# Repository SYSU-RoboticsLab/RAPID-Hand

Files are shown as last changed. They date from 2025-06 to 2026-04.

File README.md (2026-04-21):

<p align="center">
    <h1 align="center"><strong>
    RAPID Hand: A Robust, Affordable,<br>
    Perception-Integrated, Dexterous Manipulation Platform<br>
    for Generalist Robot Autonomy</strong>
    </h1>
</p>

<p align="center" style="font-size:18px;">
    <a href="https://jeffreyzhaoliang.github.io/zhaoliang-wan.github.io/"><strong>Zhaoliang Wan</strong></a>
    ·
    <a href=""><strong>Zetong Bi</strong></a>
    ·
    <a href=""><strong>Zida Zhou</strong></a>
    ·
    <a href="https://hren20.github.io/"><strong>Hao Ren</strong></a>
    ·
    <a href="https://jzengym.github.io/JZENGYM/"><strong>Yiming Zeng</strong></a>
    ·
    <a href=""><strong>Yihan Li</strong></a>
    <br>
    <a href="http://luqi.info/"><strong>Lu Qi</strong></a>
    ·
    <a href="https://people.ucas.edu.cn/~XuYang"><strong>Xu Yang</strong></a>
    ·
    <a href="https://faculty.ucmerced.edu/mhyang/"><strong>Ming-Hsuan Yang</strong></a>
    ·
    <a href="https://cse.sysu.edu.cn/teacher/ChengHui"><strong>Hui Cheng</strong></a>
</p>

<p align="center">
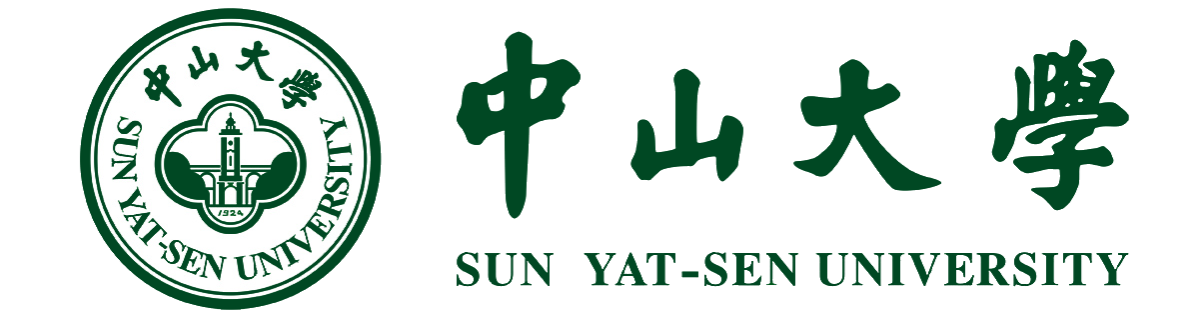
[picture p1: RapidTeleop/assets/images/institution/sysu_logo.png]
  
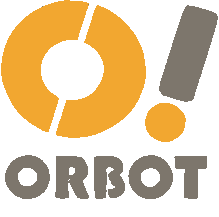
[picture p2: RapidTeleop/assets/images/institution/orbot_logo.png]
  
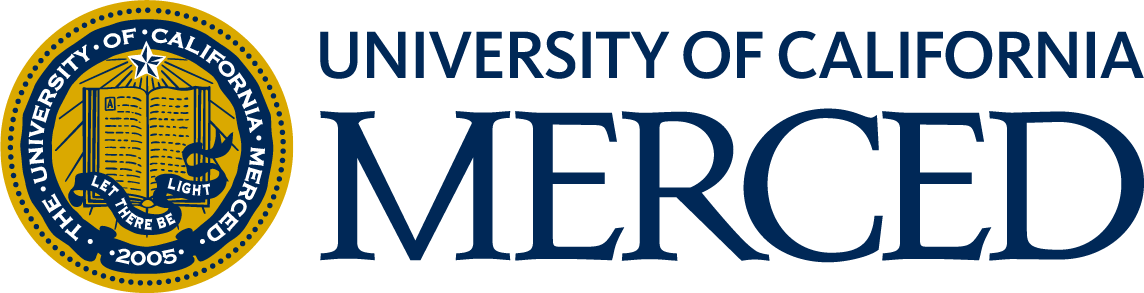
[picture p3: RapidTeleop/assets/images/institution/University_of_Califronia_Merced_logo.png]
  
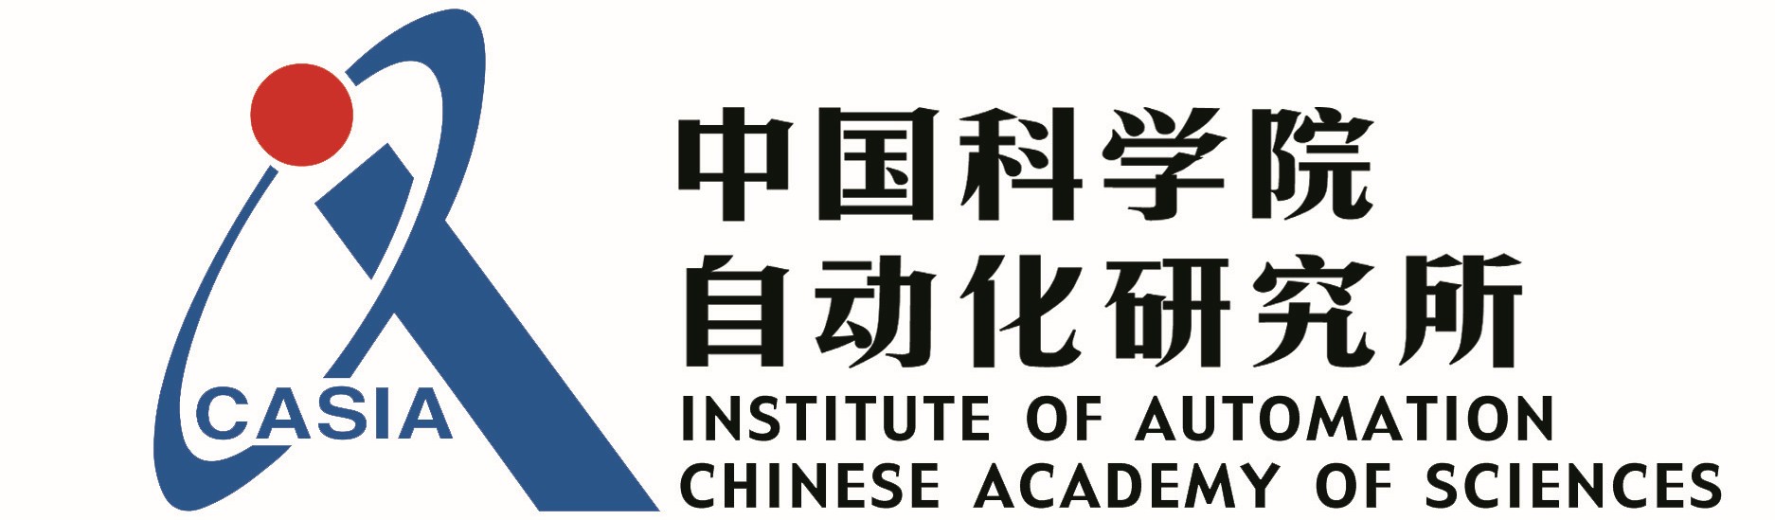
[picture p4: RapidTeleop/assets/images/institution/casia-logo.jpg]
  
</p>

<h3 align="center"> NeurIPS 2025 </h3>

<h3 align="center"><a href="https://www.arxiv.org/abs/2506.07490">Paper</a> | <a href="https://rapid-hand.github.io/">Project Page</a> | <a href="https://github.com/SYSU-RoboticsLab/RAPID-Hand/tree/main/RapidHandHardware">Hardware Design</a> | <a href="https://github.com/SYSU-RoboticsLab/RAPID-Hand/tree/main/RapidTeleop">Teleoperation</a> </a></h3>

<p align="center">
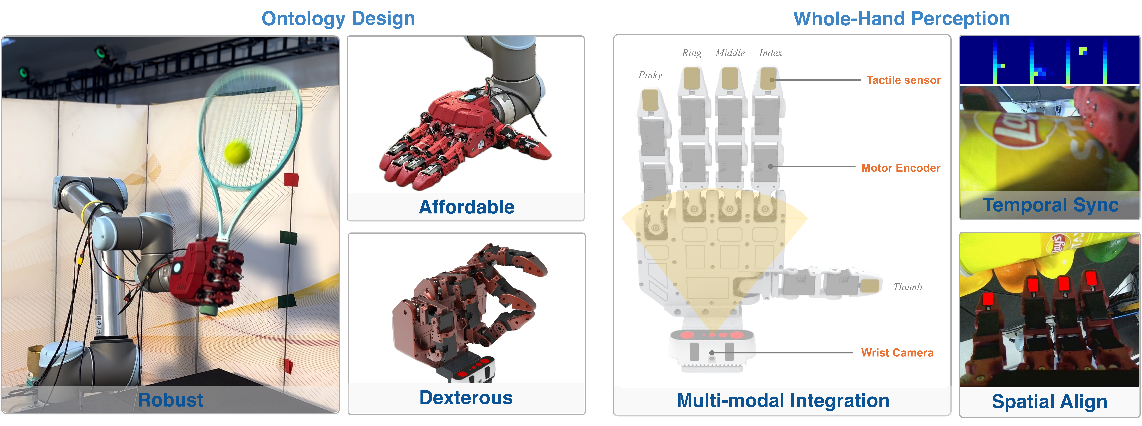
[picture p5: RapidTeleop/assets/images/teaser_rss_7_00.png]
    
</p>

## 🔥 News

- [2025-09] Our paper has been **accepted by NeurIPS 2025**! 🎉
- [2025-06] RAPID Hand full system released with mechanical, electrical, and software modules.
- [2025-06] We release the [paper](https://www.arxiv.org/abs/2506.07490) of RAPID Hand.

---

## 🏠 Introduction

This repository is an official implementation of **RAPID Hand**, which is a low-cost, high-fidelity, modular hardware-software platform for dexterous hand manipulation, consisting of:

- **RapidHandHardware**: Detailed hardware design (PCBs, 3D printable parts, bill of materials).
- **RapidTeleop**: Vision-guided teleoperation suite with intuitive user control.

It enables researchers and hobbyists to easily replicate complex hand hardware for manipulation tasks at a much lower cost.

---

## 🛠️ Installation & Usage

Please refer to the sub-repository READMEs for detailed instructions:

- 🧩 [RapidHandHardware](./RapidHandHardware/README.md): mechanical design, PCB setup, and system integration for the RAPID Hand platform.
- 🖥️ [RapidTeleop](./RapidTeleop/README.md): teleoperation interface, ROS setup, and control pipeline for both simulation and real hardware.

---

## 📝 TODO

- \[x\] Release hardware and BOM.
- \[x\] Upload software for teleop and control.
- \[ \] Extend to multiple hand variants and task types.

---

## 🔗 Citation

If you use our project, please cite:

```bibtex
@article{wan2025rapid,
  title={RAPID Hand: A Robust, Affordable, Perception-Integrated, Dexterous Manipulation Platform for Generalist Robot Autonomy},
  author={Wan, Zhaoliang and Bi, Zetong and Zhou, Zida and Ren, Hao and Zeng, Yiming and Li, Yihan and Qi, Lu and Yang, Xu and Yang, Ming-Hsuan and Cheng, Hui},
  journal={arXiv preprint arXiv:2506.07490},
  year={2025}
}
```

---

## 📄 License

This project is licensed under the [Creative Commons BY-NC-SA 4.0 License](http://creativecommons.org/licenses/by-nc-sa/4.0/).

---

## 🙏 Acknowledgements

This project was developed with help of the following codebases.
- [Tracking Streamer](https://github.com/Improbable-AI/VisionProTeleop)  
- [AnyTeleop](https://yzqin.github.io/anyteleop/)  
- [Bunny-VisionPro](https://dingry.github.io/projects/bunny_visionpro.html)  
- [HATO](https://toruowo.github.io/hato/)  
- [Orbbec-sdk](https://github.com/orbbec/pyorbbecsdk)  

We would also like to thank orbot **ORBOT** Ltd. for their support on the robot hardware and [LUSTER](https://www.luster3ds.com/content/details202_5099.html) for motion capture devices. We sincerely appreciate the contributions from all related institutions and authors.

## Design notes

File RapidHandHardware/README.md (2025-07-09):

<p align="center">
    <h1 align="center"><strong>
    RAPID Hand: A Robust, Affordable,<br>
    Perception-Integrated, Dexterous Manipulation Platform<br>
    for Generalist Robot Autonomy</strong>
    </h1>
</p>

<p align="center" style="font-size:18px;">
    <a href="https://jeffreyzhaoliang.github.io/zhaoliang-wan.github.io/"><strong>Zhaoliang Wan</strong></a>
    ·
    <a href=""><strong>Zetong Bi</strong></a>
    ·
    <a href=""><strong>Zida Zhou</strong></a>
    ·
    <a href="https://hren20.github.io/"><strong>Hao Ren</strong></a>
    ·
    <a href="https://jzengym.github.io/JZENGYM/"><strong>Yiming Zeng</strong></a>
    ·
    <a href=""><strong>Yihan Li</strong></a>
    <br>
    <a href="http://luqi.info/"><strong>Lu Qi</strong></a>
    ·
    <a href="https://people.ucas.edu.cn/~XuYang"><strong>Xu Yang</strong></a>
    ·
    <a href="https://faculty.ucmerced.edu/mhyang/"><strong>Ming-Hsuan Yang</strong></a>
    ·
    <a href="https://cse.sysu.edu.cn/teacher/ChengHui"><strong>Hui Cheng</strong></a>
</p>

<h3 align="center"><a href="https://www.arxiv.org/abs/2506.07490">Paper</a> | <a href="https://rapid-hand.github.io/">Project Page</a> | <a href="https://github.com/SYSU-RoboticsLab/RAPID-Hand/tree/main/RapidTeleop">Teleoperation</a> </a></h3>

<p align="center">
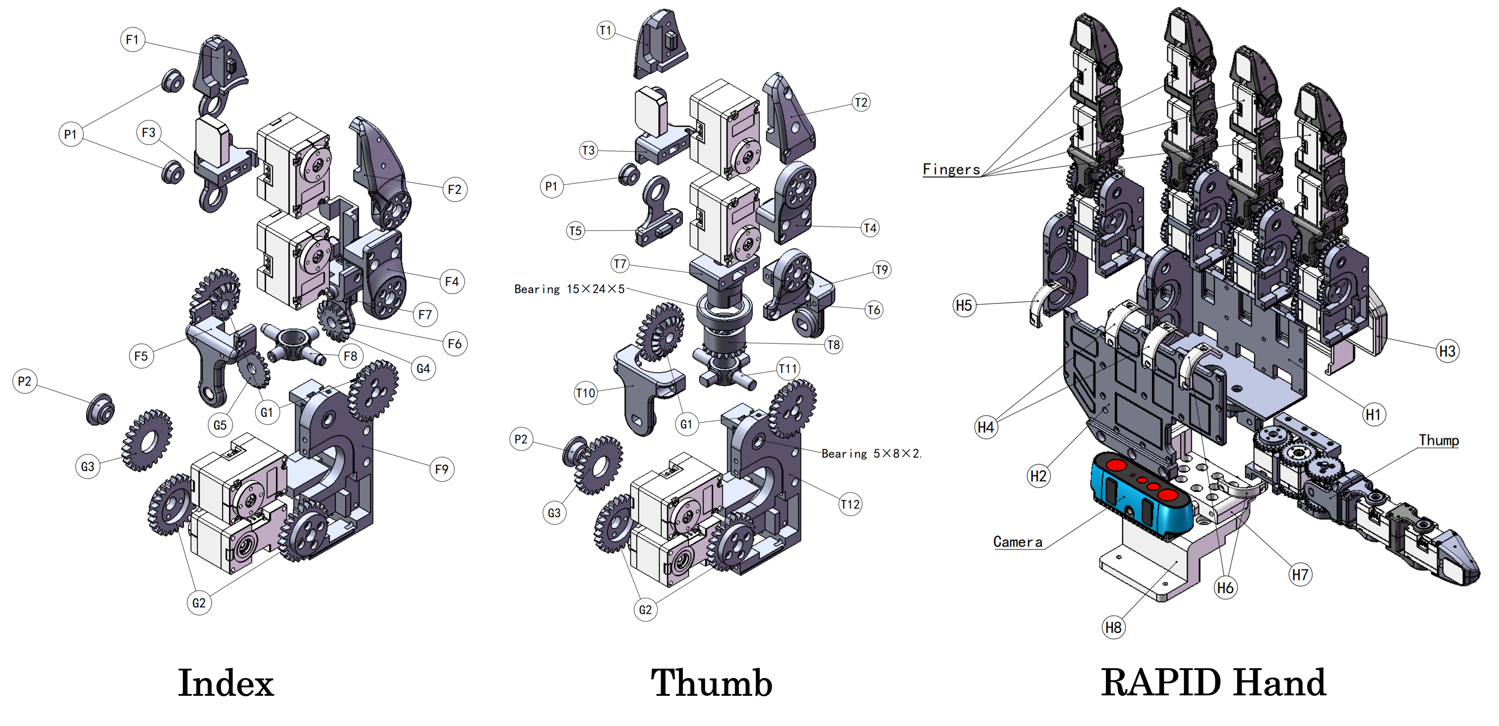
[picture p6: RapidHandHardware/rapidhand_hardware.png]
    
</p>

---

## 1. Introduction

This repository provides full open-source hardware and software resources for **RAPID Hand**. It enables reproducible development and robust sensorimotor integration for manipulation.

---

## 2. Quick Start Guide

> This section walks through the end-to-end hardware setup, including 3D printing, PCB assembly, and full system integration.

### 2.1 Mechanical Assembly

Instructions are located in the `mechanical_structure/` directory, including:

- `.STL` and `.STEP` files for 3D printing
- Servo model references and mounting instructions
- Camera and base installation guide

📎 **Goal**: Physical hand structure assembled with camera mounted.

---

### 2.2 PCB Sourcing & Assembly

PCB instructions are found in the `pcb_sync_module/` directory and include:

- `BOM_Board1_PCB1.xlsx`: Bill of Materials
- `SCH_Schematic1.pdf`: Circuit schematic

📎 **Goal**: PCB modules soldered, verified, and connected to camera/tactile sensors.

---

## 3. Software Setup & Testing

This section covers environment setup, actuator calibration, camera integration, and tactile sensor verification to ensure the system is fully functional.

### 3.1 Environment Setup

Create and initialize a Conda environment named `rapid_hand_env`:

```bash
conda create -n rapid_hand_env python=3.8
conda activate rapid_hand_env
pip install -r requirements.txt
```

---

### 3.2 Dynamixel Motor Calibration

#### ⚙️ Zero-Position Calibration

1. **Close** Dynamixel Wizard if open.
2. Mount the calibration fixture and manually align fingers into a **zero (neutral) pose**.
3. Run the calibration script (replace with actual port, e.g., `/dev/ttyUSB0`):

```bash
python motor_init -p <your_motor_port>
```

4. Verify the zero position (with the calibration fixture removed):

```bash
python motor_init -p <your_motor_port> --test
```

> The hand should return to the neutral pose without joint misalignment.

#### 🤖 Gesture Test

After calibration, run a test sequence to validate motor setup:

```bash
python motion_sequence_controller -p <your_motor_port>
```

> The hand should perform predefined gestures (e.g., curling) smoothly and without collisions.

---

### 3.3 Camera Setup and Testing

#### 🧰 SDK Installation

> For detailed installation instructions, refer to the [Official Orbbec SDK Documentation](https://orbbec.github.io/pyorbbecsdk/source/2_installation/build_the_package.html)

Run the following commands to install and export the camera SDK:

```bash
cd control/rapid_hand_control/camera_port
git submodule add https://github.com/orbbec/pyorbbecsdk.git
conda activate rapid_hand_env
bash build_sdk.sh
```

> Shared libraries will be placed in `camera_sdk/` for use.

#### 🔌 Device Connection and Test

Connect the Orbbec camera via **USB 3.0** for reliable transmission. Run:

```bash
python hello_orbbec.py
```

Expected terminal output:

```txt
Hello Orbbec!
SDK version: 2.3.5
Device info: DeviceInfo(name=Orbbec Gemini 335, ...)
```

#### 🔐 Serial Number Configuration

Copy the `serial_number` from the output above and insert it into:

```json
// rapid_hand_control/camera_port/multi_device_sync_config.json
"devices": [
  {
    "serial_number": "YOUR_SERIAL",
    "config": {
      "mode": "HARDWARE_TRIGGERING"
    }
  }
]
```

---

### 3.4 Tactile Sensor Visualization

Run the following script to monitor tactile feedback in real-time:

```bash
python tactile_visualizer -p <your_serial_port>
```

> Use this to verify the sensor layout and ensure signal consistency across all fingers.

---

## 4. FAQ & Troubleshooting

Common issues and suggested checks:

- **Motor not responding** → Check power supply and USB permissions
- **No tactile signal** → Confirm sensor wiring and PCB soldering
- **PCB not powering up** → Check voltage and shorts across power lines
- *(Feel free to contribute more entries!)*

---

## Citation

```bibtex
@article{wan2025rapid,
  title={RAPID Hand: A Robust, Affordable, Perception-Integrated, Dexterous Manipulation Platform for Generalist Robot Autonomy},
  author={Wan, Zhaoliang and Bi, Zetong and Zhou, Zida and Ren, Hao and Zeng, Yiming and Li, Yihan and Qi, Lu and Yang, Xu and Yang, Ming-Hsuan and Cheng, Hui},
  journal={arXiv preprint arXiv:2506.07490},
  year={2025}
}
```

---

## License

This project is licensed under the [Creative Commons BY-NC-SA 4.0 License](http://creativecommons.org/licenses/by-nc-sa/4.0/).

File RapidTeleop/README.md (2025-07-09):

<p align="center">
    <h1 align="center"><strong>
    RAPID Hand: A Robust, Affordable,<br>
    Perception-Integrated, Dexterous Manipulation Platform<br>
    for Generalist Robot Autonomy</strong>
    </h1>
</p>

<p align="center" style="font-size:18px;">
    <a href="https://jeffreyzhaoliang.github.io/zhaoliang-wan.github.io/"><strong>Zhaoliang Wan</strong></a>
    ·
    <a href=""><strong>Zetong Bi</strong></a>
    ·
    <a href=""><strong>Zida Zhou</strong></a>
    ·
    <a href="https://hren20.github.io/"><strong>Hao Ren</strong></a>
    ·
    <a href="https://jzengym.github.io/JZENGYM/"><strong>Yiming Zeng</strong></a>
    ·
    <a href=""><strong>Yihan Li</strong></a>
    <br>
    <a href="http://luqi.info/"><strong>Lu Qi</strong></a>
    ·
    <a href="https://people.ucas.edu.cn/~XuYang"><strong>Xu Yang</strong></a>
    ·
    <a href="https://faculty.ucmerced.edu/mhyang/"><strong>Ming-Hsuan Yang</strong></a>
    ·
    <a href="https://cse.sysu.edu.cn/teacher/ChengHui"><strong>Hui Cheng</strong></a>
</p>

<h3 align="center"><a href="https://www.arxiv.org/abs/2506.07490">Paper</a> | <a href="https://rapid-hand.github.io/">Project Page</a> | <a href="https://github.com/SYSU-RoboticsLab/RAPID-Hand/tree/main/RapidHandHardware">Hardware Design</a> </a></h3>

<p align="center">
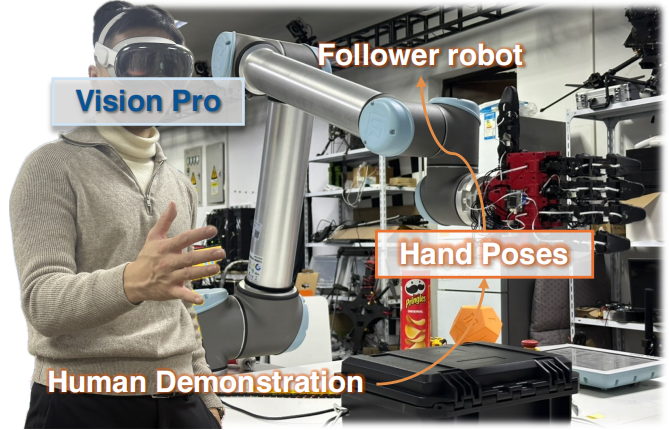
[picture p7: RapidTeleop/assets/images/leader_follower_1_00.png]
    
</p>

## 1. Introduction

This repository implements the teleoperation interface and control stack for the **RAPID Hand**. It enables real-time control of the robotic hand using motion data streamed from Vision Pro.

---

## 2. Installation & Setup Guide

### 2.1 Software selection -- OS

Currently tested and working configurations:

- ✅ Ubuntu 18.04 + ROS 1 melodic
- ✅ Ubuntu 20.04 + ROS 1 noetic

---

### 2.2 Software installation – ROS

This project relies on **ROS (Robot Operating System)** for inter-module communication.
Please install a compatible ROS distribution based on your operating system **before** building or running the code.

| Recommended Setup | Installation Guide |
| --- | --- |
| **ROS 1 – Melodic** (Ubuntu 18.04) | [wiki.ros.org/melodic/Installation](https://wiki.ros.org/melodic/Installation) |
| **ROS 1 – Noetic** (Ubuntu 20.04)  | [wiki.ros.org/noetic/Installation](https://wiki.ros.org/noetic/Installation) |

> For other ROS versions (e.g., Foxy, Iron, Rolling) or different operating systems, please refer to the official docs at [docs.ros.org](https://docs.ros.org).

Once installed, make sure to add the following line to your shell configuration file (e.g., `.bashrc`) to automatically load ROS environment variables:

```bash
source /opt/ros/<distro>/setup.bash  # Replace <distro> with your ROS distribution name
```

This ensures you can run `ros*` or `ros2*` commands in new terminal sessions.
If you encounter any ROS-related issues, first verify that your ROS environment is properly installed and sourced.

---

### 2.3 Software installation – Conda

```shell
  conda create -n rapid_teleop python=3.8
  conda activate rapid_teleop
  pip install -r requirements.txt
```

---

### 2.4 Hardware installation

#### 2.4.1 Dynamixel Motor setup

> 🛠 **Before you begin:**
> Make sure to identify your motor's serial port (e.g., `/dev/ttyUSB0`) and update it in the configuration file:
>
> ```yaml
> # File: args/robot_args/hand_args/rapid_args.yaml
> motor_port: /dev/ttyUSB0
> ```

**Calibrate the zero position**

- Before proceeding, **make sure Dynamixel Wizard is closed** and the software environment is fully set up.
- Mount the **calibration fixture** on the robotic hand and place the fingers in their intended **zero (neutral) pose**.
- Run the following command to record the current position of each motor as its **default (zero-radian) position**:

  ```shell
  # Replace <your_motor_port> with your actual device path, e.g., /dev/ttyUSB0
  python -m utils.motor_init -p <your_motor_port>
  ```
- Then verify the calibration by running:

  ```shell
  python -m utils.motor_init -p <your_motor_port> --test 
  ```

  This command sets all joint angles to zero. Visually check that the hand moves into the correct neutral pose without misalignment.

Once all motors have been installed and zeroed, run the following command to test the motor configuration:

```shell
python -m utils.motion_sequence_controller -p <your_motor_port>
```

If the robotic hand can perform preset gestures such as finger curling without any collisions or unnatural motion, the assembly and motor configuration are correct.

---

#### 2.4.2 Camera installation

> For detailed installation instructions, refer to the [Official Orbbec SDK Documentation](https://orbbec.github.io/pyorbbecsdk/source/2_installation/build_the_package.html)

**🔧 Step 1: Build and Install the Orbbec SDK**

Run the following commands to install and export the camera SDK:

```bash
cd control/rapid_hand_control/camera_port

# Add the SDK repository as a submodule (only required once)
git submodule add https://github.com/orbbec/pyorbbecsdk.git

# Activate the environment and build the SDK
conda activate rapid_teleop
bash build_sdk.sh
```

Once the build is complete, the generated shared libraries will be automatically copied to the `camera_sdk/` directory for use by the project.

**📷 Step 2: Connect the Camera and Run a Test**

Ensure the camera is properly connected to the host machine via a **USB 3.0 interface** to guarantee stable data transmission.

> To verify the connection or test the device functionality, you can use the official tool [OrbbecViewer](https://github.com/orbbec/OrbbecSDK).

After connecting the camera, run the test script:

```python
python hello_orbbec.py
```

If the SDK is installed successfully, the terminal will display output similar to:

```txt
Hello Orbbec!
SDK version: 2.3.5
Device info: DeviceInfo(name=Orbbec Gemini 335,
serial_number=CP15641000AB,
...)
```

**🧩 Step 3: Configure the Serial Number**

Copy the `serial_number` from the output and fill it into the configuration file `multi_device_sync_config.json`:

```json
// control/rapid_hand_control/camera_port/multi_device_sync_config.json
"devices": [
  {
    "serial_number": "",
    "config": {
      "mode": "HARDWARE_TRIGGERING"
    }
  }
]
```

---

#### 2.4.3 Tactile Verification

> 🛠 **Before you begin:**
> Identify the serial port used by your tactile PCB (e.g., `/dev/ttyCH341USB0`) and update the configuration:
>
> ```yaml
> # File: args/robot_args/hand_args/rapid_args.yaml
> pcb_port: /dev/ttyCH341USB0
> ```

You can visualize tactile data in real time, by running:

```shell
# Replace <your_serial_port> with your actual device path, e.g., /dev/ttyUSB0
python -m utils.tactile_visualizer -p <your_serial_port>
```

Using the serial terminal or the visualization script, you can identify the order of tactile data from each finger.
To ensure a consistent and standardized order during runtime—index, middle, ring, little, thumb—update the following mapping in the configuration file:

```yaml
# File: args/robot_args/hand_args/rapid_args.yaml
# Map tactile signals in the exact order they arrive.
# For example, if the first signal comes from the little finger (LDIP), set LDIP to 0, and so on.
tactile_order_dict:
  IDIP: 0  # Index finger
  MDIP: 3  # Middle finger
  RDIP: 1  # Ring finger
  LDIP: 2  # Little finger
  TDIP: 4  # Thumb
```

This configuration ensures the tactile data stream is correctly interpreted and remains consistent across all modules.

---

#### 2.4.4 VisionPro Configuration

1. Ensure that your host machine and the Vision Pro device are connected to the same Local Area Network (LAN).
2. Download and install the [Tracking Streamer app](https://github.com/Improbable-AI/VisionProTeleop) on your Vision Pro device.
3. Launch the Tracking Streamer app and take note of the IPv4 address displayed on the screen.
4. Open the `visionpro.yaml` configuration file and update the `avp_ip` field with the IP address you just noted:

```yaml
# args/inputstream_args/visionpro.yaml
input_stream_type: visionpro
avp_ip: 192.168.1.100
```

---

## 3. Teleoperation Test

This section guides you through running the ROS-based teleoperation system. The pipeline streams motion data from Vision Pro and supports controlling both a simulated and a real robotic hand (UR10 + RAPID Hand).

### 🔧 3.1 Start Tracking Streamer on Vision Pro

On your Vision Pro device, open the **Tracking Streamer** app and tap **Start** to begin streaming motion data.

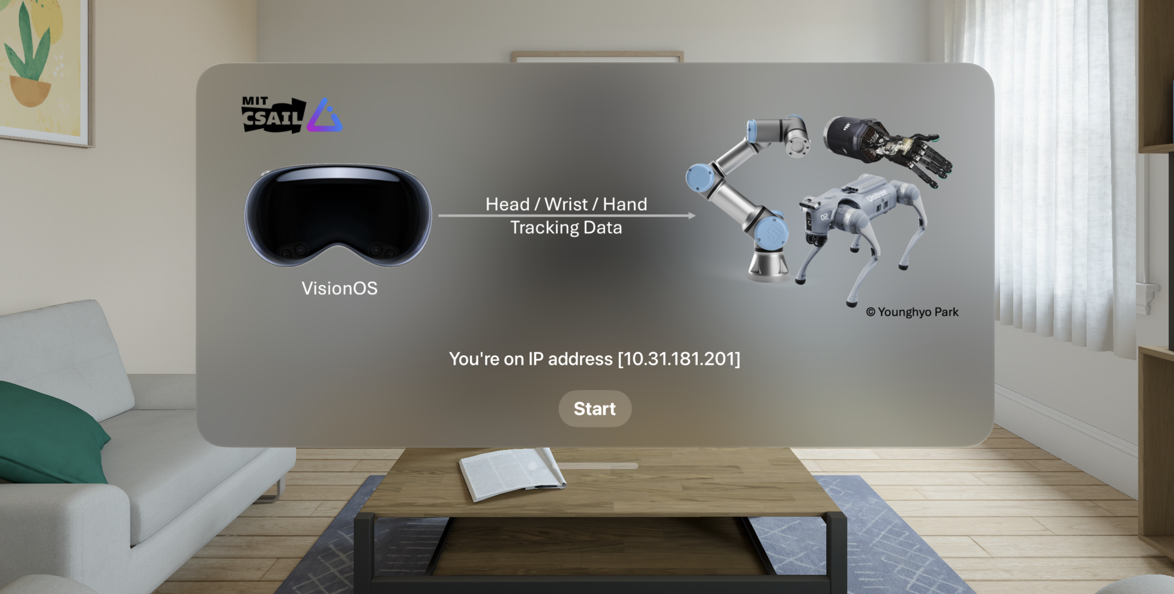
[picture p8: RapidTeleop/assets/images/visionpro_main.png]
Vision Pro Main UI (https://github.com/Improbable-AI/VisionProTeleop)


---

### 📡 3.2 Start ROS Core

```bash
roscore
```

ROS is the middleware that allows communication between all modules.

---

### 🧠 3.3 Launch the Teleoperation Node

```bash
python teleop_node.py
```

This node:

- Loads settings from `args/teleop_args.yaml`,
- Converts Vision Pro or glove motion input into robot joint commands using `TeleopProcessor`,
- Publishes joint commands to `/teleoperation/joint_angles`.

✅ **ROS topic published:**

```yaml
joint_command_topic: /teleoperation/joint_angles  # in teleop_args.yaml
```

---

### 🧪 3.4 (Optional) Launch the Simulator

```bash
python sim_node.py
```

Runs a real-time Sapien simulator that mirrors the teleoperation motion:

- Loads the robot URDF model,
- Subscribes to `/teleoperation/joint_angles`,
- Applies the motion in simulation.

Great for **visual debugging** or **testing without hardware**.

---

### 🤖 3.5 (Optional) Launch the Real Robot Node

```bash
python robot_node.py
```

This node drives the **UR10 arm** and **Rapid Hand**:

- Subscribes to `/teleoperation/joint_angles`,
- Sends real-time joint commands to the physical devices.

It can also:

- **Publish sensor data** to ROS topics,
- **Save robot data** for experiments (optional).

🗂️ **Key config entries in `teleop_args.yaml`:**

```yaml
# File: args/teleop_args.yaml
publish_config:
  publish_robot_data: true        # Whether to publish robot data to ROS topics in real time
  robot_data_topic:
    joint_topic: /robot2/joint_states            # Topic to publish robot joint angles (UR10 + Rapid Hand)
    rgb_image_topic: /camera_image               # Topic to publish RGB camera images from the hand
    tactile_topic: /tactile_data                 # Topic to publish raw tactile sensor values
    tactile_image_topic: /tactile_image          # Topic to publish 2D tactile heatmaps (image format)
    tactile_point_cloud_topic: /tactile_point_cloud  # Topic to publish 3D point cloud from tactile sensors

save_config:
  save_robot_data: False         # Whether to save robot sensor data to disk during teleoperation
  root_dir: ./data               # Root directory to store data if saving is enabled
  task_dir: test_data            # Subfolder name under root_dir to organize the current experiment's data

```

---

## Citaton

```bibtex
@article{wan2025rapid,
  title={RAPID Hand: A Robust, Affordable, Perception-Integrated, Dexterous Manipulation Platform for Generalist Robot Autonomy},
  author={Wan, Zhaoliang and Bi, Zetong and Zhou, Zida and Ren, Hao and Zeng, Yiming and Li, Yihan and Qi, Lu and Yang, Xu and Yang, Ming-Hsuan and Cheng, Hui},
  journal={arXiv preprint arXiv:2506.07490},
  year={2025}
}
```

---

## Licence

This project is licensed under the [Creative Commons BY-NC-SA 4.0 License](http://creativecommons.org/licenses/by-nc-sa/4.0/).

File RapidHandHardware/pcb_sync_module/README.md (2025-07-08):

# 🔌 PCB Synchronization Module

This directory contains all design and manufacturing files for reproducing the **PCB sync module** of the RAPID Hand.

📎 **Expected outcome**: A fully soldered and assembled PCB that interfaces with **5 tactile sensors** and a **camera**.

---

## 📁 Directory Structure

```txt
pcb_sync_module/
│
├─ README.md                                # This file
│
└─ pcb_sourcing/                            # Contains all PCB design and production files
    ├─ BOM_Board1_PCB1.xlsx                 # Bill of Materials for PCB components
    ├─ PCB_Layout.pdf                       # PCB layout with Camera/USB-C interfaces
    └─ SCH_Schematic1.pdf                   # Full schematic of the board
```

---

## 🧩 Connector Guide: Camera and Tactile Sensors

Based on the schematic and board layout:

- **Tactile Sensor Connections**:The PCB includes **five FPC connectors** (FPC5–FPC9), each labeled and routed through `PB6_SCL` and `PB7_SDA`, indicating shared I2C bus operation.
- **Camera Interface**:Located near the right edge, labeled as **Camera**, routed through pin `PB4`.

## ✅ Functionality Test After Assembly

Once all tactile sensors are connected and the PCB is configured:

1. Connect the PCB to your PC via **USB**.
2. Open a serial terminal (e.g., `minicom`, `screen`, `cutecom`).
3. Send a single byte: `0xFF`.
4. If successful, the MCU will respond with:
   - **5 consecutive data frames** — each frame consists of exactly  **96 bytes** , corresponding to one tactile sensor.
   - Each data frame is immediately followed by a **1-byte delimiter** (end marker), indicating the end of that frame.
5. Apply different levels of pressure to test taxel response.

This allows you to **validate sensor communication** and **confirm board-level functionality**.

---

## 🔗 Citation

```bibtex
@article{wan2025rapid,
  title={RAPID Hand: A Robust, Affordable, Perception-Integrated, Dexterous Manipulation Platform for Generalist Robot Autonomy},
  author={Wan, Zhaoliang and Bi, Zetong and Zhou, Zida and Ren, Hao and Zeng, Yiming and Li, Yihan and Qi, Lu and Yang, Xu and Yang, Ming-Hsuan and Cheng, Hui},
  journal={arXiv preprint arXiv:2506.07490},
  year={2025}
}
```

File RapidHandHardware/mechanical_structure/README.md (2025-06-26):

# 🦾 Mechanical Structure Assembly Guide

This directory contains all the necessary resources for building the **mechanical structure of the RAPID hand**, including 3D models, BOM (Bill of Materials), and detailed assembly instructions.

📌 **Goal**: Assemble the full RAPID hand structure and mount the camera module.

---

## 📁 Directory Structure

```txt
mechanical_structure/
│
├─ BOM_and_Assembly_Guide.pdf      # Main reference for mechanical BOM & visual instructions
├─ calibration_board.STL           # STL file for the calibration_board
├─ README.md                       # This file
│
├─ rapidhand_description/          # ROS description package: URDF model, meshes, config & launch files
│
├─ 3D Printed Parts/               # STL files for all 3D printed mechanical parts
│   └─ F1.STL ~ T12.STL            # Fingers, thumb, palm, etc.
│
└─ Model/                          # STEP files for CAD and visualization
    └─ Finger.STEP
        thumb.STEP
        rapidhand.STEP
```

---

## 🧩 Bill of Materials (BOM)

The mechanical assembly consists of three main subassemblies:

### 🔹 1. Finger Module (×4)

| Category | Name | Quantity |
| --- | --- | --- |
| Electronic Devices | Motor | 4 |
| | Tactile Sensor | 1 |
| 3D Printed Parts | F1–F9, G1–G5, P1–P2 | 1 each (G1,G2,P1×2) |
| Mechanical Components | Screw M2×4 | 20 |
| | Screw M2×10 | 16 |
| | Screw M2.5×12 | 6 |
| | Screw M3×6 | 3 |
| | Bearing 5×8×2.5 | 4 |

---

### 🔹 2. Thumb Module (×1)

| Category | Name | Quantity |
| --- | --- | --- |
| Electronic Devices | Motor | 4 |
| | Tactile Sensor | 1 |
| 3D Printed Parts | T1–T12, G1–G3, P1–P2 | 1 each (G1,G2,P1×2) |
| Mechanical Components | Screw M2×4 | 16 |
| | Screw M2×10 | 16 |
| | Screw M2.5×12 | 8 |
| | Screw M3×6 | 3 |
| | Bearing 5×8×2.5 | 2 |
| | Bearing 15×24×5 | 1 |

---

### 🔹 3. Palm & Integration

| Category | Name | Quantity |
| --- | --- | --- |
| Electronic Devices | Camera | 1 |
| 3D Printed Parts | H1–H8 | 1 each (H4,H6×2) |
| Mechanical Components | Screw M2.5×10 | 50 |
| | Screw M4×12 | 6 |
| | Screw M3×6 | 2 |
| Subassemblies | Finger | 4 |
| | Thumb | 1 |

---

## 🔧 Assembly Instructions

1. 📘 **Refer to `BOM_and_Assembly_Guide.pdf`**

   - This document provides exploded views and labeled diagrams for each module: Finger, Thumb, and Palm.
2. 🧱 **3D Print Components**

   - Print all `.STL` files from `3D Printed Parts/`. Make sure the dimensions are accurate and tolerances are respected.
3. 🆔 **Configure Dynamixel Servo IDs**

   Before assembling motors into the hand, assign each Dynamixel servo a **unique ID**:

   - Connect a **single** motor to the U2D2 controller and the computer via USB.
   - Open [**Dynamixel Wizard 2.0**](https://emanual.robotis.com/docs/en/software/dynamixel/dynamixel_wizard2/).
   - In **Option → Preferences**, set:
     - **Protocol:** 2.0
     - **Baudrate:** Select **all available baudrates** for initial detection
     - **Port:** Your serial device (e.g., ttyUSB0 or COMx)
   - Click `Scan` to find connected motors.
   - Assign a new unique ID using the recommended scheme:

   <table>
      <tr>
        <th style="width: 105px; text-align: center;">Finger</th>
        <th style="width: 105px; text-align: center;">MCP-Side</th>
        <th style="width: 105px; text-align: center;">MCP-Forward</th>
        <th style="width: 105px; text-align: center;">PIP</th>
        <th style="width: 105px; text-align: center;">DIP</th>
      </tr>
      <tr>
        <td style="text-align: center;">Index</td>
        <td style="text-align: center;">0</td>
        <td style="text-align: center;">1</td>
        <td style="text-align: center;">2</td>
        <td style="text-align: center;">3</td>
      </tr>
      <tr>
        <td style="text-align: center;">Middle</td>
        <td style="text-align: center;">4</td>
        <td style="text-align: center;">5</td>
        <td style="text-align: center;">6</td>
        <td style="text-align: center;">7</td>
      </tr>
      <tr>
        <td style="text-align: center;">Ring</td>
        <td style="text-align: center;">8</td>
        <td style="text-align: center;">9</td>
        <td style="text-align: center;">10</td>
        <td style="text-align: center;">11</td>
      </tr>
      <tr>
        <td style="text-align: center;">Little</td>
        <td style="text-align: center;">12</td>
        <td style="text-align: center;">13</td>
        <td style="text-align: center;">14</td>
        <td style="text-align: center;">15</td>
      </tr>
      <tr>
        <td style="text-align: center;">Thumb</td>
        <td style="text-align: center;">16</td>
        <td style="text-align: center;">17</td>
        <td style="text-align: center;">18</td>
        <td style="text-align: center;">19</td>
      </tr>
    </table>

   - Also set each motor’s **Bus Baud Rate** to **4,000,000 bps (4Mbps)**.
   - Repeat for all 20 motors before mechanical installation.
4. 🪛 **Assemble Fingers & Thumb**

   - Use the visual guides to install motors, gears, sensors, and linkages.
   - Follow the screw size and placement as annotated.
   - Ensure bearings and gear alignments are precise to avoid mechanical jamming.
5. 🖐️ **Assemble Palm & Integrate Modules**

   - Mount the assembled fingers and thumb onto the palm base (`H1–H8`).
   - Fix the camera unit as shown in the diagrams.
   - Tighten using the correct screw lengths to avoid cracking plastic parts.
6. 🧩 **Fit & Finalize**

   - Once all modules are fixed to the palm, verify smooth motion.
   - Optionally, adjust with lubricant or sanding for tight joints.

<!-- 7. 🎯 **Calibrate Zero Position**

   - Ensure all mechanical installation is complete.
   - Mount the **calibration fixture** and place all fingers in their intended **zero (neutral) pose**.
   - Run:

     ```bash
     python -m utils.motor_init
     ```

   - Verify with:

     ```bash
     python -m utils.motor_init --test
     ```

     This sets all joint angles to zero. Visually confirm proper alignment.

Once all motors have been installed and zeroed, run the following command to test the motor configuration:

```shell
python -m utils.motion_sequence_controller
```

If the robotic hand can perform preset gestures such as finger curling without any collisions or unnatural motion, the assembly and motor configuration are correct. -->

---

## ⚠️ Notes & Precautions

- Ensure all 3D printed parts are clean of support material before assembly.
- Pay close attention to screw lengths—using the wrong length can strip the plastic or block movement.
- Tolerances may vary by printer; minor manual adjustments (filing, drilling) may be necessary.
- Avoid overtightening screws around motors and sensors to prevent damage.
- Validate fit and mechanical movement before powering on the system.

---

## 🔗 Citation

```bibtex
@article{wan2025rapid,
  title={RAPID Hand: A Robust, Affordable, Perception-Integrated, Dexterous Manipulation Platform for Generalist Robot Autonomy},
  author={Wan, Zhaoliang and Bi, Zetong and Zhou, Zida and Ren, Hao and Zeng, Yiming and Li, Yihan and Qi, Lu and Yang, Xu and Yang, Ming-Hsuan and Cheng, Hui},
  journal={arXiv preprint arXiv:2506.07490},
  year={2025}
}
```

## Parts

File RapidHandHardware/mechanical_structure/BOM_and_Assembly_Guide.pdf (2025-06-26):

# BOM of each Finger

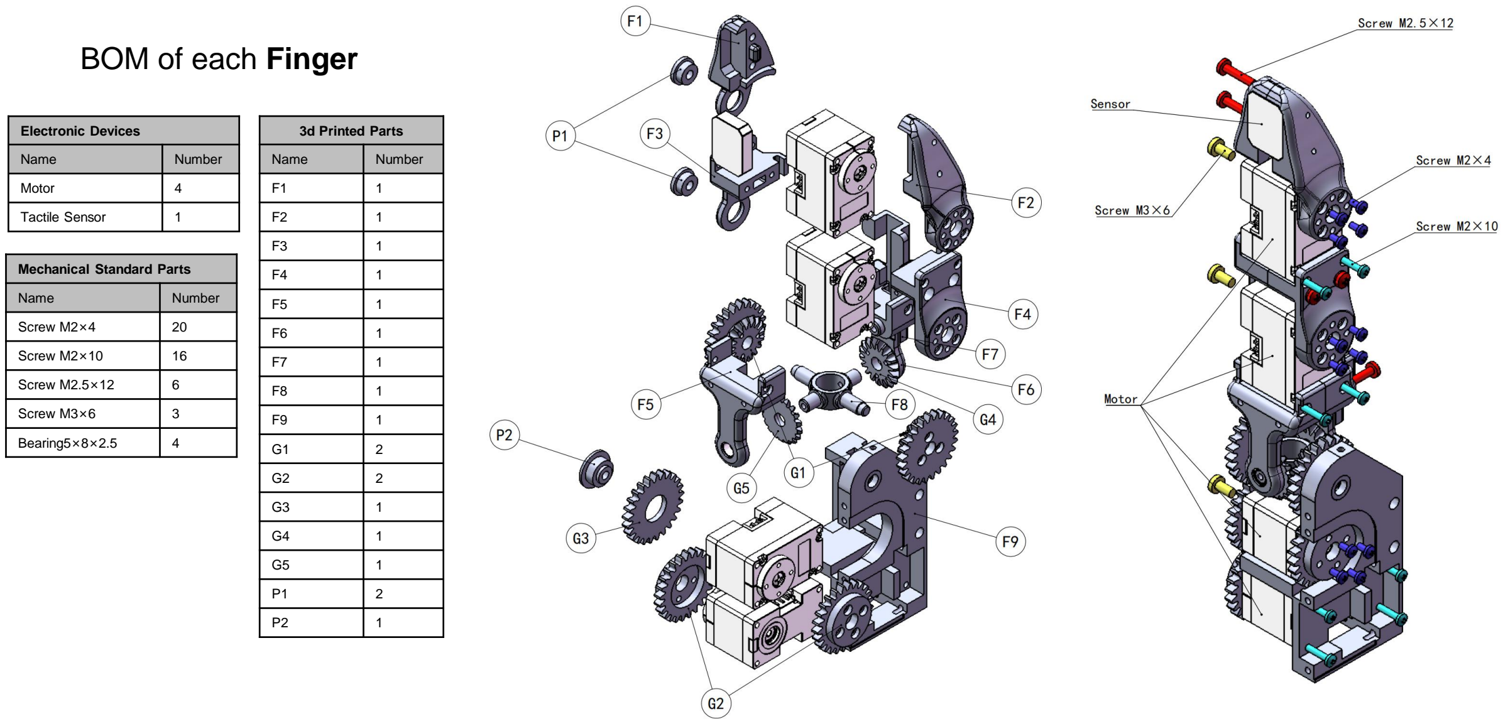
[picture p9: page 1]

Mechanical Standard Parts

Name | Number
Screw M2×4 | 20
Screw M2×10 | 16
Screw M2.5×12 | 6
Screw M3×6 | 3
Bearing5×8×2.5 | 4

3d Printed Parts

Name | Number
F1 | 1
F2 | 1
F3 | 1
F4 | 1
F5 | 1
F6 | 1
F7 | 1
F8 | 1
F9 | 1
G1 | 2
G2 | 2
G3 | 1
G4 | 1
G5 | 1
P1 | 2
P2 | 1

Electronic Devices

Name | Number
Motor | 4
Tactile Sensor | 1

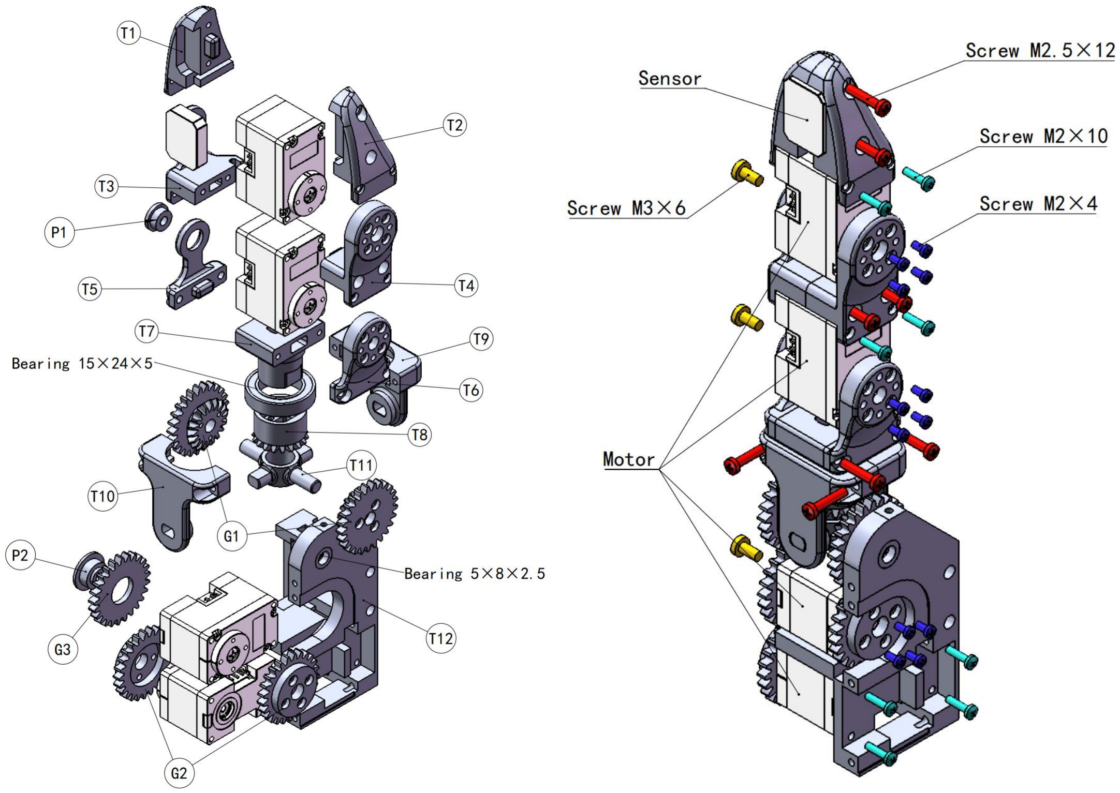
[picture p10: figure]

Mechanical Standard Parts

Name | Number
Screw M2×4 | 16
Screw M2×10 | 16
Screw M2.5×12 | 8
Screw M3×6 | 3
Bearing5×8×2.5 | 2
Bearing15×24×5 | 1

3d Printed Parts

Name | Number
T1 | 1
T2 | 1
T3 | 1
T4 | 1
T5 | 1
T6 | 1
T7 | 1
T8 | 1
T9 | 1
T10 | 1
T11 | 1
T12 | 1
G1 | 2
G2 | 2
G3 | 1
P1 | 2
P2 | 1

Electronic Devices

Name | Number
Motor | 4
Tactile Sensor | 1

# BOM of each Thumb

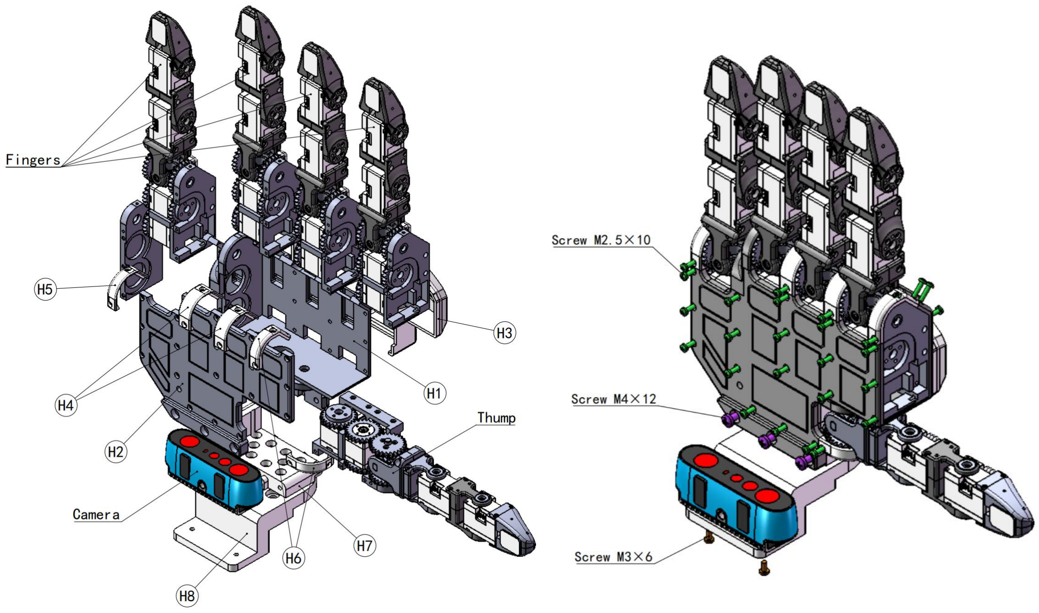
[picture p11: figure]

3d Printed Parts

Name | Number
H1 | 1
H2 | 1
H3 | 1
H4 | 2
H5 | 1
H6 | 2
H7 | 1
H8 | 1

Electronic Devices

Name | Number
Camera | 1

Mechanical Standard Parts

Name | Number
Screw M2.5×10 | 50
Screw M4×12 | 6
Screw M3×6 | 2

# BOM of Palm

Subassembly

Name | Number
Finger | 4
Thumb | 1

# Total BOM

Electronic Devices

Name | Number
Motor | 20
Tactile Sensor | 5
Camera | 1

3d Printed Parts

Name | Number
F1 | 5
F2 | 5
F3 | 5
F4 | 5
F5 | 5
F6 | 5
F7 | 5
F8 | 5
F9 | 5
T1 | 1
T2 | 1
T3 | 1
T4 | 1
T5 | 1
T6 | 1
T7 | 1
T8 | 1
T9 | 1
T10 | 1
T11 | 1
T12 | 1

Mechanical Standard Parts

Name | Number
Screw M2×4 | 116
Screw M2×10 | 96
Screw M2.5×12 | 38
Screw M3×6 | 18
Screw M2.5×10 | 50
Screw M4×12 | 6
Screw M3×6 | 2
Bearing5×8×2.5 | 22
Bearing15×24×5 | 1

Mechanical Standard Parts

3d Printed Parts

Name | Number
H1 | 1
H2 | 1
H3 | 1
H4 | 2
H5 | 1
H6 | 2
H7 | 1
H8 | 1
G1 | 12
G2 | 12
G3 | 6
G4 | 5
G5 | 5
P1 | 12
P2 | 6

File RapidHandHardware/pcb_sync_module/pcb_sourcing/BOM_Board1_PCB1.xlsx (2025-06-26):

No. | Quantity | Comment | Designator | Footprint | Value | Manufacturer Part | Manufacturer | Supplier Part | Supplier
1 | 12 | 100nF | C23,C24,C25,C26,C27,C28,C35,C41,C42,C54,C87,C89 | C0402 | 100nF | CL05B104KO5NNNC | SAMSUNG(三星) | C1525 | LCSC
2 | 1 | 1uF | C29 | C0402 | 1uF | CL05A105KP5NNNC | SAMSUNG(三星) | C14445 | LCSC
3 | 2 | 2.2uF | C30,C31 | C0402 | 2.2uF | CL05A225KO5NQNC | SAMSUNG(三星) | C170151 | LCSC
4 | 2 | 20pF | C32,C33 | C0402 | 20pF | GRM1555C1H200JA01D | muRata(村田) | C76959 | LCSC
5 | 2 | 10uF | C88,C90 | C0402 | 10uF | CL05A106MP5NUNC | SAMSUNG(三星) | C315248 | LCSC
6 | 2 | WAFER-GH1.25-2PWB | Camera,Servo | CONN-TH_2P-P1.25_XUNPU_WAFER-GH1.25-2PWB |  | WAFER-GH1.25-2PWB | XUNPU(讯普) | C3029377 | LCSC
7 | 5 | AFC42-S04FMA-1H | FPC1,FPC2,FPC3,FPC4,FPC5 | FFC-SMD_4P-P0.50_AFC42-S04FMA-1H |  | AFC42-S04FMA-1H | JS(钜硕电子) | C466528 | LCSC
8 | 1 | PZ254V-11-04P | H5 | HDR-TH_4P-P2.54-V-M |  | PZ254V-11-04P | XFCN(兴飞) | C2691448 | LCSC
9 | 1 | NCD0805B2 | PB1 | LED0805-R-RD |  | NCD0805B2 | 国星光电 | C84259 | LCSC
10 | 1 | NCD0805G1 | PB2 | LED0805-R-RD |  | NCD0805G1 | 国星光电 | C84260 | LCSC
11 | 1 | NCD0805R1 | PWR | LED0805-R-RD |  | NCD0805R1 | 国星光电 | C84256 | LCSC
12 | 1 | S8050-J3Y | Q3 | SOT-23-3_L3.0-W1.7-P0.95-LS2.9-BR |  | S8050-J3Y | MDD(辰达半导体) | C364312 | LCSC
13 | 4 | 1kΩ | R6,R7,R24,R36 | R0402 | 1kΩ | ERJ2RKF1001X | PANASONIC(松下) | C242161 | LCSC
14 | 1 | 10kΩ | R21 | R0603 | 10kΩ | RC0603FR-0710KL | YAGEO(国巨) | C98220 | LCSC
15 | 5 | 10kΩ | R23,R37,R38,R39,R40 | R0603 | 10kΩ | 0603WAF1002T5E | UNI-ROYAL(厚声) | C25804 | LCSC
16 | 3 | 4.7kΩ | R33,R34,R42 | R0402 | 4.7kΩ | ERJ2RKF4701X | PANASONIC(松下) | C400631 | LCSC
17 | 1 | 0Ω | R41 | R0402 | 0Ω | ERJ2GE0R00X | PANASONIC(松下) | C242160 | LCSC
18 | 1 | TS-1088-AR02016 | SW3 | SW-SMD_L3.9-W3.0-P4.45 |  | TS-1088-AR02016 | XUNPU(讯普) | C720477 | LCSC
19 | 4 | 螺丝孔 | TP1,TP2,TP3,TP4 | M2螺丝
20 | 1 | STM32H743VIT6 | U4 | LQFP-100_L14.0-W14.0-P0.50-LS16.0-BL |  | STM32H743VIT6 | ST(意法半导体) | C114409 | LCSC
21 | 1 | CH340N | U6 | SOP-8_L4.9-W3.9-P1.27-LS6.0-BL |  | CH340N | WCH(南京沁恒) | C2977777 | LCSC
22 | 1 | SN74LVC2G241DCTR | U16 | SSOP-8_L3.0-W2.8-P0.65-LS4.0-BL |  | SN74LVC2G241DCTR | TI(德州仪器) | C2676069 | LCSC
23 | 1 | AMS1117-3.3 | U28 | SOT-223-3_L6.5-W3.4-P2.30-LS7.0-BR |  | AMS1117-3.3 | AMS | C6186 | LCSC
24 | 1 | TYPE-C-31-M-12 | USBC1 | USB-C_SMD-TYPE-C-31-M-12 |  | TYPE-C-31-M-12 | 韩国韩荣 | C165948 | LCSC
25 | 1 | 12MHz | X2 | OSC-SMD_4P-L3.2-W2.5-BL | 12MHz | X322512MSB4SI | YXC(扬兴晶振) | C9002 | LCSC

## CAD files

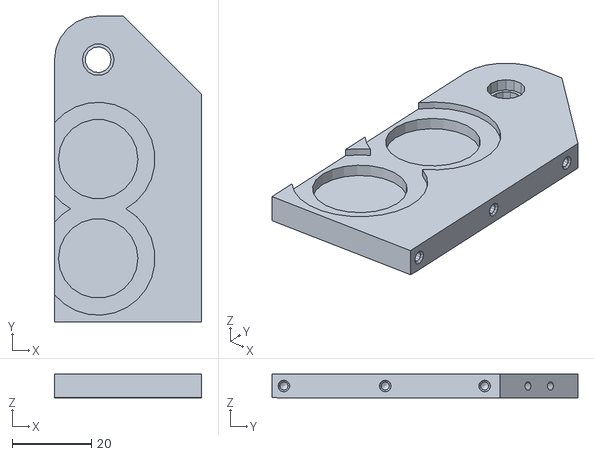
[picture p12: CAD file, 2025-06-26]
RapidHandHardware/mechanical_structure/3D Printed Parts/H3.STL
37.0 x 77.0 x 6.00

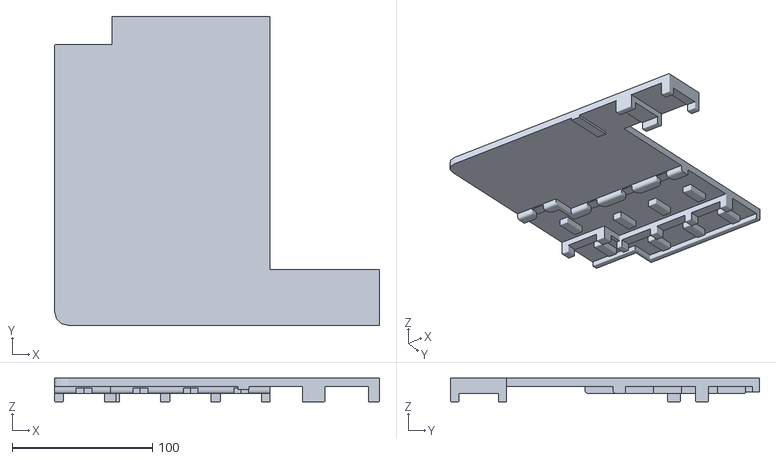
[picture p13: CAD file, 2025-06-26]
RapidHandHardware/mechanical_structure/calibration_board.STL
232.0 x 220.5 x 17.0

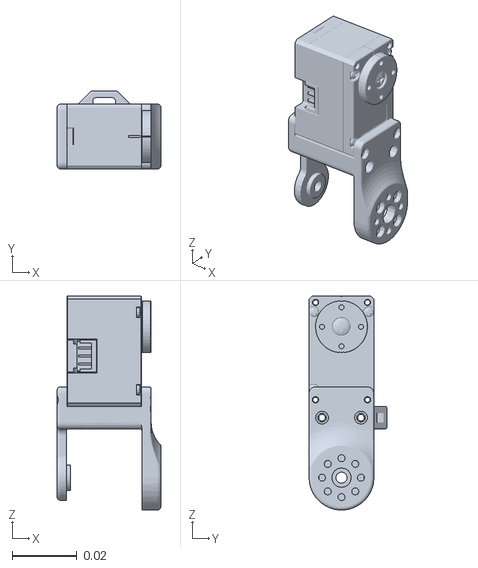
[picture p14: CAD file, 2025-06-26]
RapidHandHardware/mechanical_structure/rapidhand_description/meshes/RPIP.STL
0.032 x 0.024 x 0.066

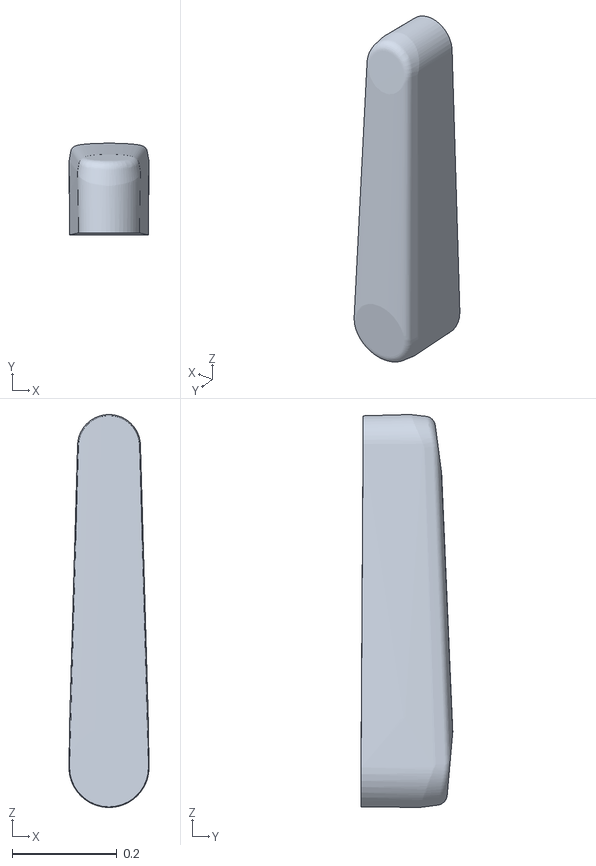
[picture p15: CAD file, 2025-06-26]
RapidTeleop/assets/robots/arms/ur10e/meshes/collision/upperarm.obj
0.153 x 0.175 x 0.749

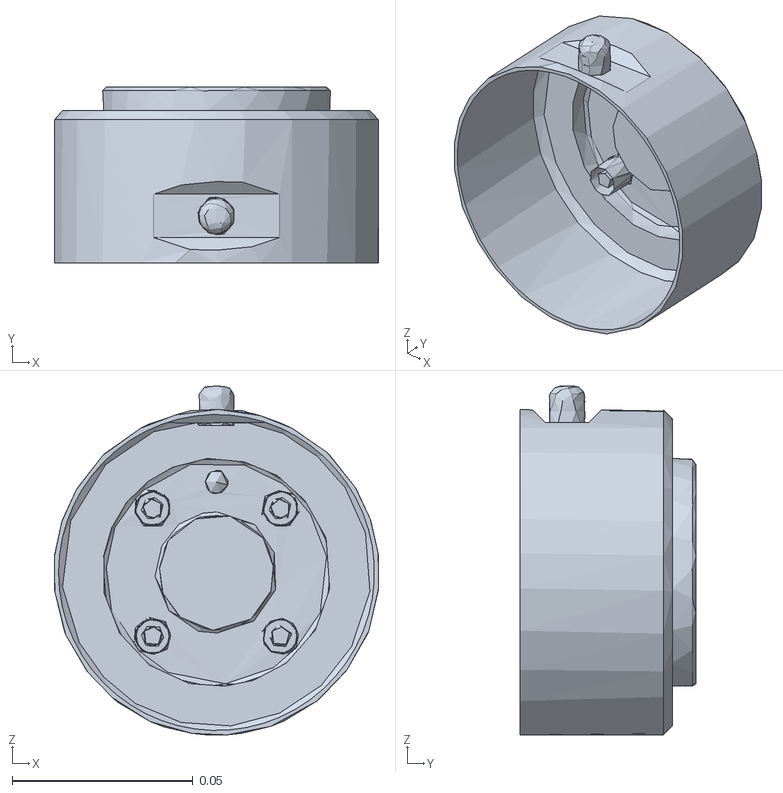
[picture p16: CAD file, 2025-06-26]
RapidTeleop/assets/robots/arms/ur10e/meshes/visual/wrist3.obj
0.0897 x 0.0488 x 0.0966

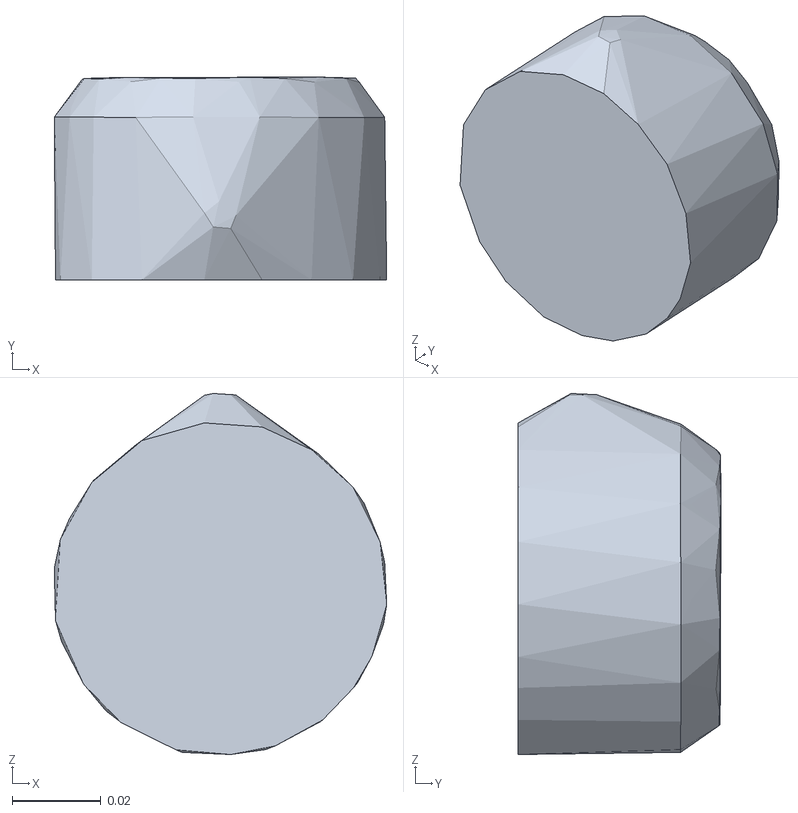
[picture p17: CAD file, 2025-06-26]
RapidTeleop/assets/robots/arms/ur5e/meshes/collision/wrist3.obj
0.0751 x 0.0458 x 0.0816

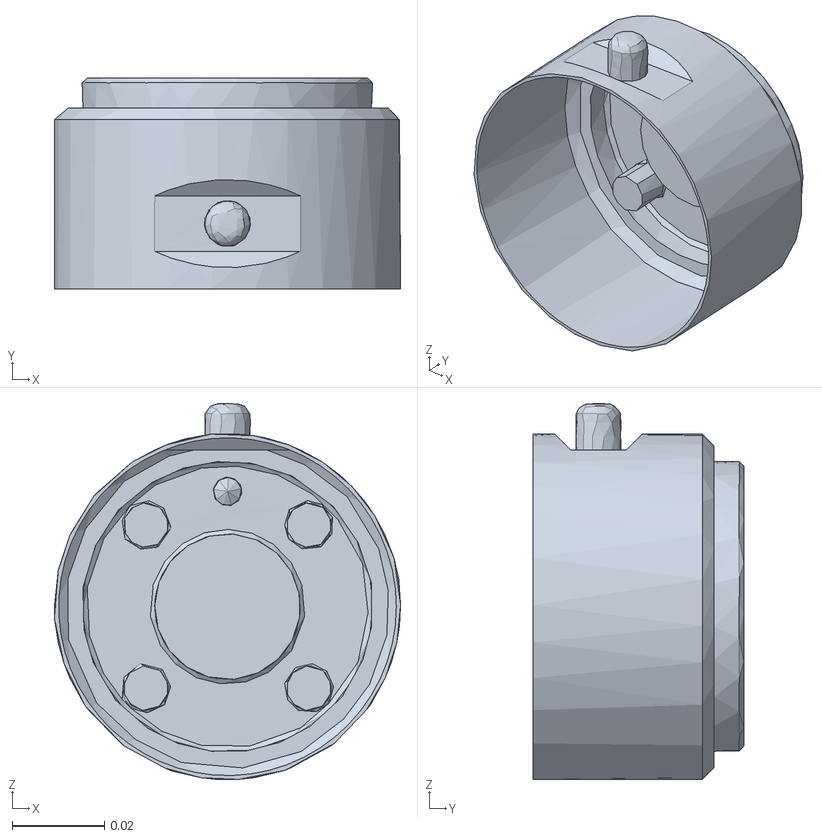
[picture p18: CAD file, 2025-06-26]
RapidTeleop/assets/robots/arms/ur5e/meshes/visual/wrist3.obj
0.0751 x 0.0458 x 0.0816

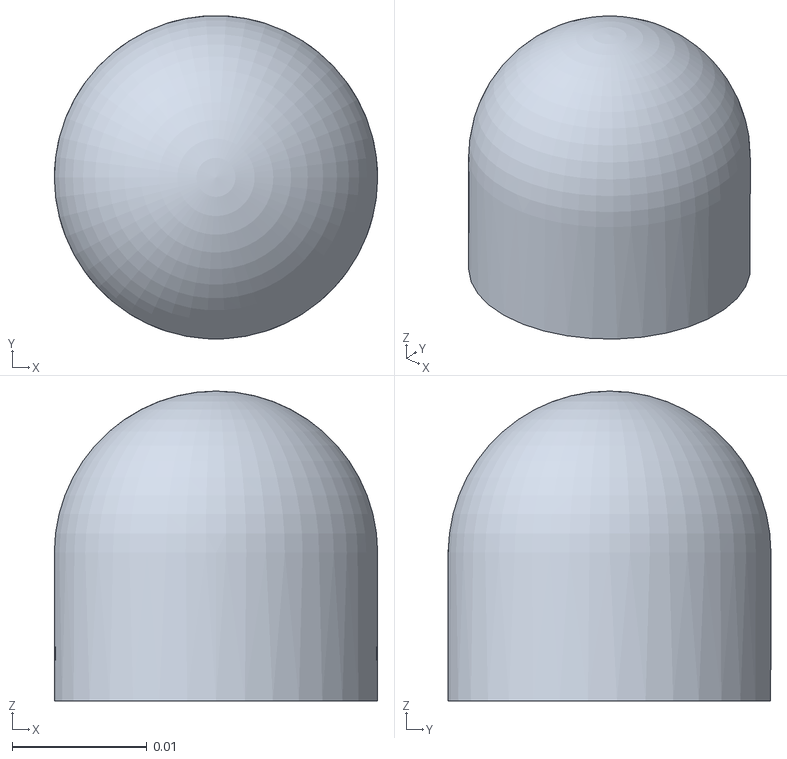
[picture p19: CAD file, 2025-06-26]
RapidTeleop/assets/robots/hands/allegro_hand/meshes/collision/link_tip.obj
0.024 x 0.024 x 0.023

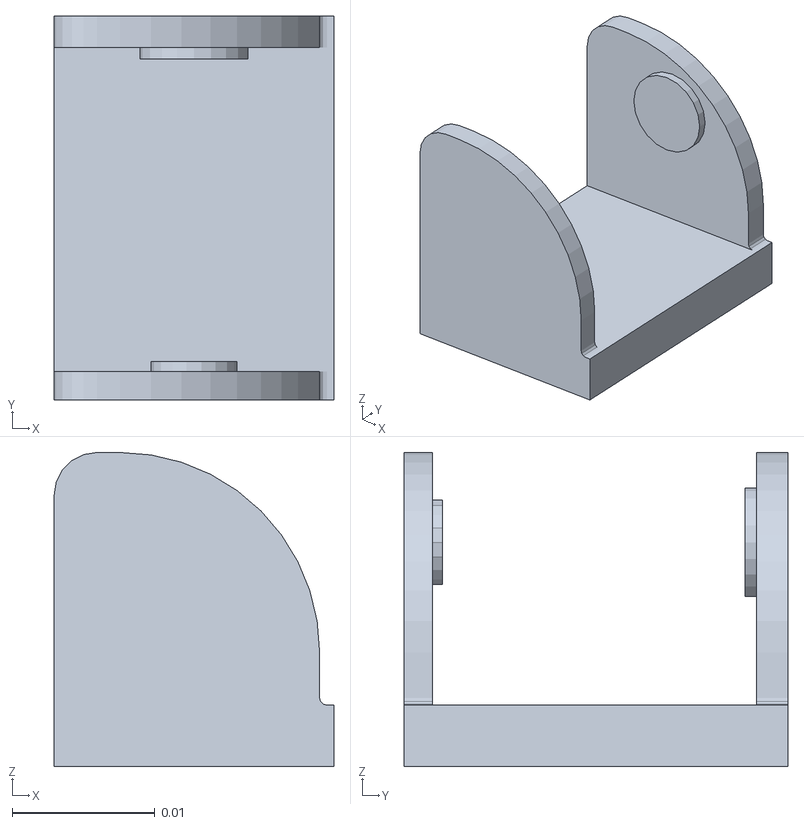
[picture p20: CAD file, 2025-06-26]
RapidTeleop/assets/robots/hands/allegro_hand/meshes/visual/link_13.0.obj
0.0196 x 0.0269 x 0.022

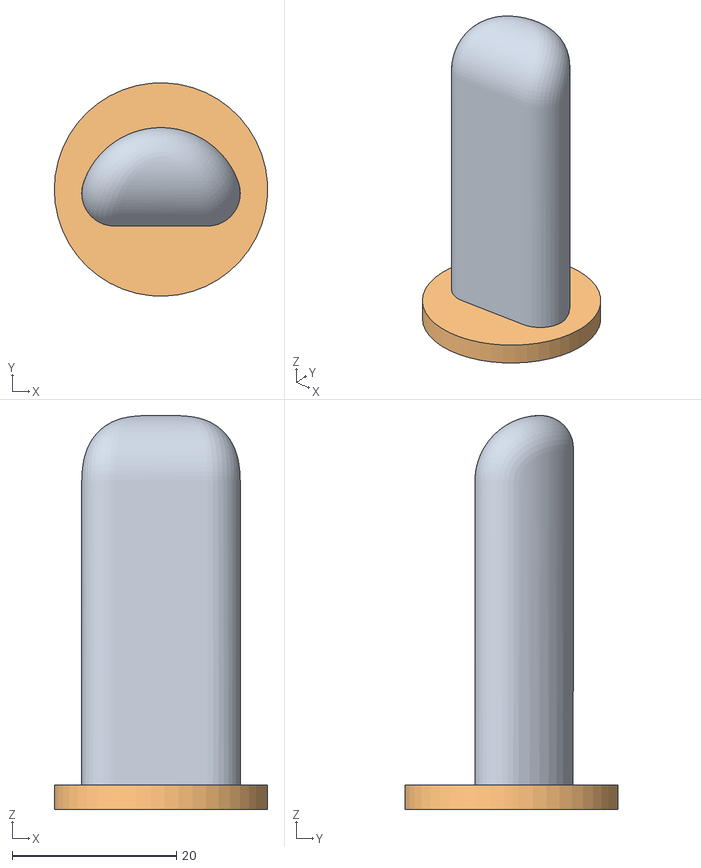
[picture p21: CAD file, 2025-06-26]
RapidTeleop/assets/robots/hands/allegro_hand/variation/meshes/collision/longer_finger_tip.obj
26.0 x 26.0 x 48.0
geometry_0
geometry_1

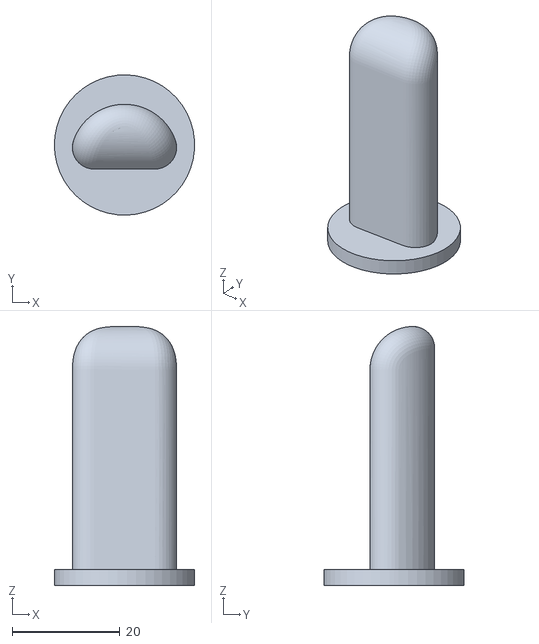
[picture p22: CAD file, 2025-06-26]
RapidTeleop/assets/robots/hands/allegro_hand/variation/meshes/visual/longer_finger_tip.obj
26.0 x 26.0 x 48.0

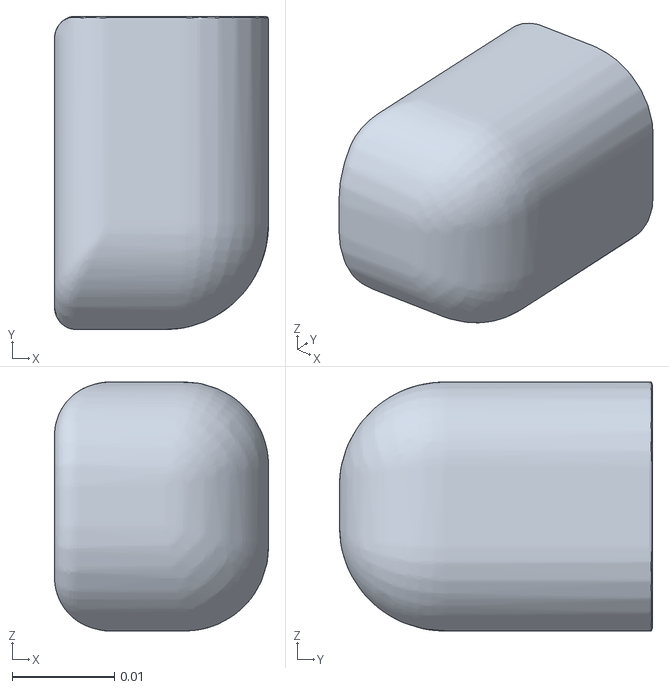
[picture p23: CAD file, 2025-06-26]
RapidTeleop/assets/robots/hands/leap_hand/meshes/collision/white_tip.obj
0.0209 x 0.0306 x 0.0243

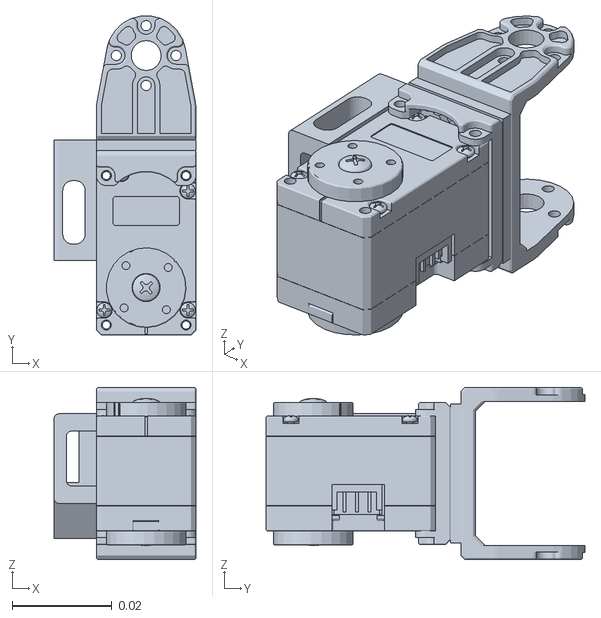
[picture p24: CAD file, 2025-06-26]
RapidTeleop/assets/robots/hands/leap_hand/meshes/visual/thumb_dip.obj
0.0285 x 0.064 x 0.0346

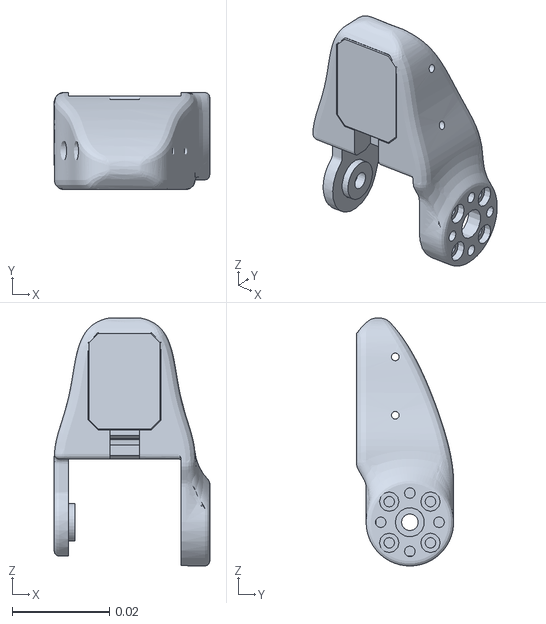
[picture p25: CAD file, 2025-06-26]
RapidTeleop/assets/robots/hands/rapid_hand/meshes/IDIP.STL
0.032 x 0.02 x 0.051

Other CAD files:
RapidHandHardware/mechanical_structure/3D Printed Parts/F5.STL
RapidHandHardware/mechanical_structure/rapidhand_description/meshes/RMCPF.STL
RapidTeleop/assets/robots/arms/ur10e/meshes/collision/base.obj
RapidTeleop/assets/robots/arms/ur10e/meshes/visual/base.obj
RapidHandHardware/mechanical_structure/3D Printed Parts/F1.STL
RapidHandHardware/mechanical_structure/3D Printed Parts/F2.STL
RapidHandHardware/mechanical_structure/3D Printed Parts/F3.STL
RapidHandHardware/mechanical_structure/3D Printed Parts/F4.STL
RapidHandHardware/mechanical_structure/3D Printed Parts/F6.STL
RapidHandHardware/mechanical_structure/3D Printed Parts/F7.STL
RapidHandHardware/mechanical_structure/3D Printed Parts/F8.STL
RapidHandHardware/mechanical_structure/3D Printed Parts/F9.STL
RapidHandHardware/mechanical_structure/3D Printed Parts/G1.STL
RapidHandHardware/mechanical_structure/3D Printed Parts/G2.STL
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

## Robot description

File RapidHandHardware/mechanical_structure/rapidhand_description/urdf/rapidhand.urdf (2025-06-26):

<?xml version="1.0" encoding="utf-8"?>
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
<robot name="rapidhand">
  <link name="BASE">
    <inertial>
      <origin xyz="-0.00487361644963443 0.00202576490845328 0.0533472117698908" rpy="0 0 0" />
      <mass value="0.440289695299581" />
      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
    </inertial>
    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
  </link>
  <link name="TMCPF">
    <inertial>
      <origin xyz="5.43874579400638E-09 0.000173367279422285 0.0134848473102515" rpy="0 0 0" />
      <mass value="0.00867255670420181" />
      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
    </inertial>
    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
  </link>
  <joint name="TF" type="revolute">
    <origin xyz="0.036 -0.004 0.043" rpy="0 1.5708 0" />
    <parent link="BASE" />
    <child link="TMCPF" />
    <axis xyz="-1 0 0" />
    <limit lower="-3.14" upper="3.14" effort="1" velocity="1" />
  </joint>
  <link name="TMCPS">
    <inertial>
      <origin xyz="0.00113278662589469 -1.13908234303239E-08 -0.00229033918513943" rpy="0 0 0" />
      <mass value="0.00961656020732061" />
      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
    </inertial>
    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
  </link>
  <joint name="TS" type="revolute">
    <origin xyz="0 0 0.0309" rpy="0 0 0" />
    <parent link="TMCPF" />
    <child link="TMCPS" />
    <axis xyz="0 -1 0" />
    <limit lower="-3.14" upper="3.14" effort="1" velocity="1" />
  </joint>
  <link name="TPIP">
    <inertial>
      <origin xyz="0.00115636106302726 0.0001035074072121 0.0147895764840127" rpy="0 0 0" />
      <mass value="0.0218638036213291" />
      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
    </inertial>
    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
  </link>
  <joint name="TP" type="revolute">
    <origin xyz="0 0 0.0185" rpy="0 0 0" />
    <parent link="TMCPS" />
    <child link="TPIP" />
    <axis xyz="-1 0 0" />
    <limit lower="-3.14" upper="3.14" effort="1" velocity="1" />
  </joint>
  <link name="TDIP">
    <inertial>
      <origin xyz="0.000385304884610346 -0.000805905719972057 0.0184635035729084" rpy="0 0 0" />
      <mass value="0.025657649089922" />
      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
    </inertial>
    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
  </link>
  <joint name="TD" type="revolute">
    <origin xyz="0 0 0.0465" rpy="0 0 0" />
    <parent link="TPIP" />
    <child link="TDIP" />
    <axis xyz="-1 0 0" />
    <limit lower="-3.14" upper="3.14" effort="1" velocity="1" />
  </joint>
  <link name="IMCPF">
    <inertial>
      <origin xyz="-1.23449232967976E-07 -1.55233664823548E-07 1.03178869920173E-07" rpy="0 0 0" />
      <mass value="0.00105509319213642" />
      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
    </inertial>
    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
  </link>
  <joint name="IF" type="revolute">
    <origin xyz="0.054 -0.004 0.13" rpy="0 0 0" />
    <parent link="BASE" />
    <child link="IMCPF" />
    <axis xyz="-1 0 0" />
    <limit lower="-3.14" upper="3.14" effort="1" velocity="1" />
  </joint>
  <link name="IMCPS">
    <inertial>
      <origin xyz="0.00051151655399137 0.00128219675748885 0.0360582073884051" rpy="0 0 0" />
      <mass value="0.0255680145005863" />
      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
    </inertial>
    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
  </link>
  <joint name="IS" type="revolute">
    <origin xyz="0 0 0" rpy="0 0 0" />
    <parent link="IMCPF" />
    <child link="IMCPS" />
    <axis xyz="0 1 0" />
    <limit lower="-3.14" upper="3.14" effort="1" velocity="1" />
  </joint>
  <link name="IPIP">
    <inertial>
      <origin xyz="0.00115558034102659 0.000110062274357295 0.0317104165010226" rpy="0 0 0" />
      <mass value="0.0218638098074725" />
      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
    </inertial>
    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
  </link>
  <joint name="IP" type="revolute">
    <origin xyz="0 0 0.052" rpy="0 0 0" />
    <parent link="IMCPS" />
    <child link="IPIP" />
    <axis xyz="-1 0 0" />
    <limit lower="-3.14" upper="3.14" effort="1" velocity="1" />
  </joint>
  <link name="IDIP">
    <inertial>
      <origin xyz="0.000735870667299736 -0.00251219154785661 0.021014755592917" rpy="0 0 0" />
      <mass value="0.0103515223793345" />
      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
    </inertial>
    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
  </link>
  <joint name="ID" type="revolute">
    <origin xyz="0 0 0.0465" rpy="0 0 0" />
    <parent link="IPIP" />
    <child link="IDIP" />
    <axis xyz="1 0 0" />
    <limit lower="-3.14" upper="3.14" effort="1" velocity="1" />
  </joint>
  <link name="MMCPF">
    <inertial>
      <origin xyz="-1.23449232967976E-07 -1.55233664825283E-07 1.03178869920173E-07" rpy="0 0 0" />
      <mass value="0.00105509319213642" />
      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
    </inertial>
    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
  </link>
  <joint name="MF" type="revolute">
    <origin xyz="0.018 -0.004 0.13" rpy="0 0 0" />
    <parent link="BASE" />
    <child link="MMCPF" />
    <axis xyz="-1 0 0" />
    <limit lower="-3.14" upper="3.14" effort="1" velocity="1" />
  </joint>
  <link name="MMCPS">
    <inertial>
      <origin xyz="0.000511516467769143 0.00128219694955495 0.0360582071081458" rpy="0 0 0" />
      <mass value="0.0255680149320248" />
      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
    </inertial>
    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
  </link>
  <joint name="MS" type="revolute">
    <origin xyz="0 0 0" rpy="0 0 0" />
    <parent link="MMCPF" />
    <child link="MMCPS" />
    <axis xyz="0 1 0" />
    <limit lower="-3.14" upper="3.14" effort="1" velocity="1" />
  </joint>
  <link name="MPIP">
    <inertial>
      <origin xyz="0.00115558034097 0.000110062274357156 0.0317104165010227" rpy="0 0 0" />
      <mass value="0.0218638098074725" />
      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
    </inertial>
    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
  </link>
  <joint name="MP" type="revolute">
    <origin xyz="0 0 0.052" rpy="0 0 0" />
    <parent link="MMCPS" />
    <child link="MPIP" />
    <axis xyz="-1 0 0" />
    <limit lower="-3.14" upper="3.14" effort="1" velocity="1" />
  </joint>
  <link name="MDIP">
    <inertial>
      <origin xyz="0.00073587003347144 -0.0025121912941592 0.0210147562316098" rpy="0 0 0" />
      <mass value="0.0103515217937735" />
      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
    </inertial>
    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
  </link>
  <joint name="MD" type="revolute">
    <origin xyz="0 0 0.0465" rpy="0 0 0" />
    <parent link="MPIP" />
    <child link="MDIP" />
    <axis xyz="1 0 0" />
    <limit lower="-3.14" upper="3.14" effort="1" velocity="1" />
  </joint>
  <link name="RMCPF">
    <inertial>
      <origin xyz="-1.23449232974915E-07 -1.55233664811405E-07 1.03178869892417E-07" rpy="0 0 0" />
      <mass value="0.00105509319213642" />
      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
    </inertial>
    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
  </link>
  <joint name="RF" type="revolute">
    <origin xyz="-0.018 -0.004 0.13" rpy="0 0 0" />
    <parent link="BASE" />
    <child link="RMCPF" />
    <axis xyz="-1 0 0" />
    <limit lower="-3.14" upper="3.14" effort="1" velocity="1" />
  </joint>
  <link name="RMCPS">
    <inertial>
      <origin xyz="0.000511516543022492 0.00128219675749102 0.0360582073884084" rpy="0 0 0" />
      <mass value="0.0255680145005759" />
      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
    </inertial>
    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
  </link>
  <joint name="RS" type="revolute">
    <origin xyz="0 0 0" rpy="0 0 0" />
    <parent link="RMCPF" />
    <child link="RMCPS" />
    <axis xyz="0 1 0" />
    <limit lower="-3.14" upper="3.14" effort="1" velocity="1" />
  </joint>
  <link name="RPIP">
    <inertial>
      <origin xyz="0.00115558034102733 0.000110062274356899 0.0317104165010224" rpy="0 0 0" />
      <mass value="0.0218638098074725" />
      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
    </inertial>
    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
  </link>
  <joint name="RP" type="revolute">
    <origin xyz="0 0 0.052" rpy="0 0 0" />
    <parent link="RMCPS" />
    <child link="RPIP" />
    <axis xyz="-1 0 0" />
    <limit lower="-3.14" upper="3.14" effort="1" velocity="1" />
  </joint>
  <link name="RDIP">
    <inertial>
      <origin xyz="0.000735869975292142 -0.00251219127106798 0.0210147562227153" rpy="0 0 0" />
      <mass value="0.0103515217591085" />
      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
    </inertial>
    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
  </link>
  <joint name="RD" type="revolute">
    <origin xyz="0 0 0.0465" rpy="0 0 0" />
    <parent link="RPIP" />
    <child link="RDIP" />
    <axis xyz="1 0 0" />
    <limit lower="-3.14" upper="3.14" effort="1" velocity="1" />
  </joint>
  <link name="LMCPF">
    <inertial>
      <origin xyz="-1.23449232974915E-07 -1.55233664811405E-07 1.03178869906295E-07" rpy="0 0 0" />
      <mass value="0.00105509319213642" />
      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
    </inertial>
    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
  </link>
  <joint name="LF" type="revolute">
    <origin xyz="-0.058 -0.004 0.11" rpy="0 0 0" />
    <parent link="BASE" />
    <child link="LMCPF" />
    <axis xyz="-1 0 0" />
    <limit lower="-3.14" upper="3.14" effort="1" velocity="1" />
  </joint>
  <link name="LMCPS">
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

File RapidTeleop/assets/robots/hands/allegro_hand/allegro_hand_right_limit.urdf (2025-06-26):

<?xml version="1.0" encoding="utf-8"?>
<robot name="allegro_right">
  <link name="allegro_base_link">
    <inertial>
      <mass value="0.4154"/>
      <origin rpy="0 0 0" xyz="0 0 0"/>
      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
    </inertial>
    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
  </link> 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
  <link name="palm"/>
  <joint name="palm_joint" type="fixed">
    <parent link="allegro_base_link"/>
    <child link="palm"/>
    <origin rpy="0.00000 -0.00000 0.00000" xyz="0 0 -0.065"/>
  </joint> 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
  <link name="wrist"/>
  <joint name="wrist_joint" type="fixed">
    <origin rpy="0 0 0" xyz="0 0 -0.03"/>
    <parent link="palm"/>
    <child link="wrist"/>
  </joint>
  <link name="link_0.0">
    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
    <inertial>
      <mass value="0.0119"/>
      <origin xyz="0 0 0" rpy="0 0 0"/>
      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
    </inertial>
  </link>
  <joint name="joint_0.0" type="revolute">
    <axis xyz="0 0 1"/>
    <limit effort="10" lower="-0.47" upper="0.47" velocity="3.14"/>
    <parent link="allegro_base_link"/>
    <child link="link_0.0"/>
    <origin rpy="-0.08726646255 0 0" xyz="0 0.0435 -0.001542"/>
  </joint>
  <link name="link_1.0">
    <inertial>
      <mass value="0.065"/>
      <origin xyz="0 0 0" rpy="0 0 0"/>
      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
    </inertial>
    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
  </link>
  <joint name="joint_1.0" type="revolute">
    <limit effort="10" lower="-0.196" upper="1.61" velocity="3.14"/>
    <axis xyz="0 1 0"/>
    <parent link="link_0.0"/>
    <child link="link_1.0"/>
    <origin xyz="0 0 0.0164"/>
  </joint>
  <link name="link_2.0">
    <inertial>
      <mass value="0.0355"/>
      <origin xyz="0 0 0" rpy="0 0 0"/>
      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
    </inertial>
    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
  </link>
  <joint name="joint_2.0" type="revolute">
    <axis xyz="0 1 0"/>
    <limit effort="10" lower="-0.174" upper="1.709" velocity="3.14"/>
    <parent link="link_1.0"/>
    <child link="link_2.0"/>
    <origin xyz="0 0 0.054"/>
  </joint>
  <link name="link_3.0">
    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
    <inertial>
      <origin rpy="0 0 0" xyz="0 0 0.01335"/>
      <mass value="0.02"/>
      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
    </inertial>
  </link>
  <joint name="joint_3.0" type="revolute">
    <axis xyz="0 1 0"/>
    <limit effort="10" lower="-0.227" upper="1.618" velocity="3.14"/>
    <parent link="link_2.0"/>
    <child link="link_3.0"/>
    <origin xyz="0 0 0.0384"/>
  </joint>
  <link name="link_3.0_tip">
    <inertial>
      <mass value="0.0168"/>
      <origin xyz="0 0 0" rpy="0 0 0"/>
      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
    </inertial>
    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
  </link>
  <joint name="joint_3.0_tip" type="fixed">
    <parent link="link_3.0"/>
    <child link="link_3.0_tip"/>
    <origin rpy="0 0 0" xyz="0 0 0.0387"/>
  </joint>
  <link name="link_4.0">
    <inertial>
      <mass value="0.005"/>
      <origin xyz="0 0 0"/>
      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
    </inertial>
    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
  </link>
  <joint name="joint_4.0" type="revolute">
    <axis xyz="0 0 1"/>
    <limit effort="10" lower="-0.47" upper="0.47" velocity="3.14"/>
    <parent link="allegro_base_link"/>
    <child link="link_4.0"/>
    <origin rpy="0.0 0 0" xyz="0 0 0.0007"/>
  </joint>
  <link name="link_5.0">
    <inertial>
      <mass value="0.065"/>
      <origin xyz="0 0 0" rpy="0 0 0"/>
      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
    </inertial>
    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
  </link>
  <joint name="joint_5.0" type="revolute">
    <limit effort="10" lower="-0.196" upper="1.61" velocity="3.14"/>
    <axis xyz="0 1 0"/>
    <parent link="link_4.0"/>
    <child link="link_5.0"/>
    <origin xyz="0 0 0.0164"/>
  </joint>
  <link name="link_6.0">
    <inertial>
      <mass value="0.0355"/>
      <origin xyz="0 0 0" rpy="0 0 0"/>
      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
    </inertial>
    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
  </link>
  <joint name="joint_6.0" type="revolute">
    <axis xyz="0 1 0"/>
    <limit effort="10" lower="-0.174" upper="1.709" velocity="3.14"/>
    <parent link="link_5.0"/>
    <child link="link_6.0"/>
    <origin xyz="0 0 0.054"/>
  </joint>
  <link name="link_7.0">
    <inertial>
      <mass value="0.0388"/>
      <origin xyz="0 0 0" rpy="0 0 0"/>
      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
    </inertial>
    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
  </link>
  <joint name="joint_7.0" type="revolute">
    <axis xyz="0 1 0"/>
    <limit effort="10" lower="-0.227" upper="1.618" velocity="3.14"/>
    <parent link="link_6.0"/>
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

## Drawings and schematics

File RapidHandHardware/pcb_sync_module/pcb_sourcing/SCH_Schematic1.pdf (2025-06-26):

# ST-LINK

# TYPE-C-31-M-12 GND

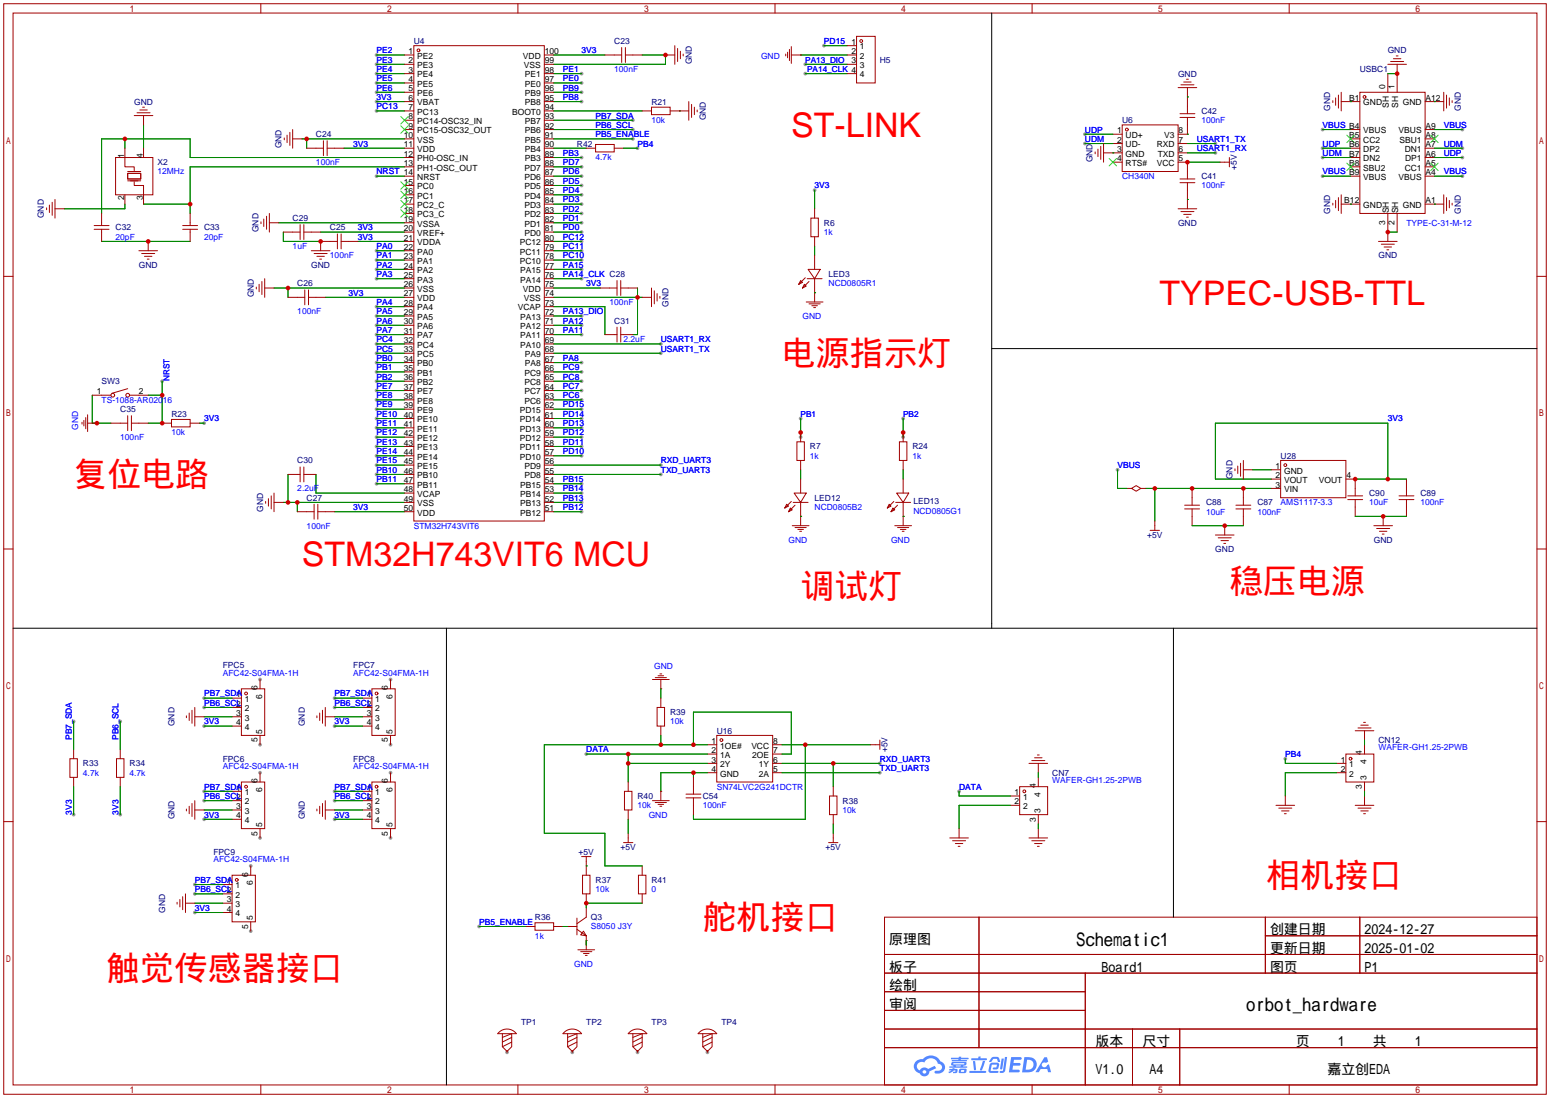
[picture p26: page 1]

原理图 | Schematic1 | 创建日期 | 2024-12-27

更新日期 | 2025-01-02

板子 | Board1 | 图页 | P1
绘制 | | orbot_hardware
审阅

V1.0 | A4 | 嘉立创EDA

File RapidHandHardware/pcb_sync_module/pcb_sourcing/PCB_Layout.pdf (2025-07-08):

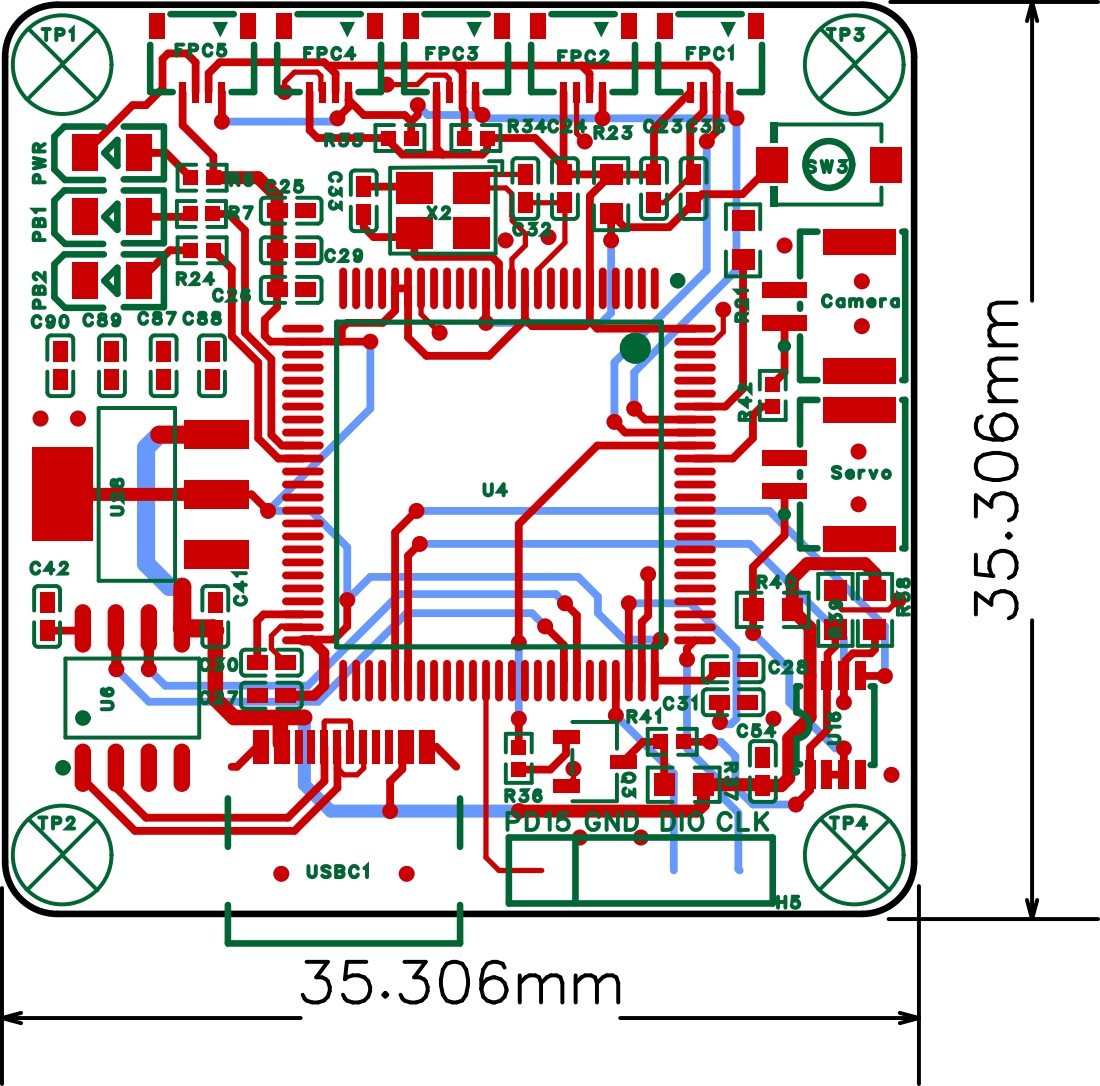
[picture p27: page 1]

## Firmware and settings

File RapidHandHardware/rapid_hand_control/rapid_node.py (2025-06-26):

import numpy as np
import cv2
import time
import os
import threading


class RapidNode:
    """
    Core data aggregation interface for the RapidHand platform.

    - Manages servo (U2D2) initialization and kinematics.
    - Collects PCB tactile data and aligns into 3D positions.
    - Retrieves RGB-D image from Orbbec camera (optional).
    """

    num_joint: int = 20
    tactile_tensor_shape: tuple[int, int, int] = (5, 12, 8)
    tactile_order_str: list[str] = ["IDIP", "MDIP", "RDIP", "LDIP", "TDIP"]

    def __init__(
        self,
        motor_port: str,
        pcb_port: str,
        use_camera: bool,
        tactile_order_dict: dict,
        joint_command_order_list: list,
    ):
        self.use_motor = self._check_port(motor_port, "motor_port")
        self.use_pcb = self._check_port(pcb_port, "pcb_port")
        self.use_camera = use_camera and self.use_pcb
        self.tactile_order_dict = tactile_order_dict

        self.hand_joint_positions = np.zeros(self.num_joint)
        self.hand_joint_velocity = np.zeros(self.num_joint)
        self.hand_joint_current = np.zeros(self.num_joint)
        self.tactile_tensor = np.zeros(self.tactile_tensor_shape)
        self.tactile_tensor_3D = np.zeros((*self.tactile_tensor_shape, 4))
        self.rgb_image_array = np.zeros((1, 2, 2, 3), dtype=np.uint8)
        self.depth_image_array = np.zeros((1, 2, 2))

        if self.use_motor:
            self._init_motor(motor_port, joint_command_order_list)

        if self.use_pcb:
            self._init_pcb(pcb_port)

        if self.use_camera:
            self._init_camera()

        print("[RapidNode] Initialized successfully.")

    def _init_motor(self, port: str, joint_order: list):
        from servo_driver.rapid_driver import RapidDriver
        from control import PinocchioHandControl

        self.motor_driver = RapidDriver(port=port)
        self.motor_driver.set_pos(np.zeros(self.num_joint))

        self.hand_model = PinocchioHandControl(
            hand_name="rapid_hand", robot_urdf_file="rapid_hand/rapid_hand_right.urdf"
        )

        self.real2pin = [
            joint_order.index(name) for name in self.hand_model.get_joint_names()
        ]

        self.tactile_order_list = [
            self.tactile_order_dict[finger] for finger in self.tactile_order_str
        ]

        self._load_tactile_positions()

    def _load_tactile_positions(self):
        import pandas as pd
        import re

        def parse_cell(cell):
            nums = re.findall(r"-?\d+\.?\d*", cell)
            return [float(x) * 1e-3 for x in nums] + [1]

        filepath = os.path.abspath(
            os.path.join(os.path.dirname(__file__), "tactile_relative_position.xlsx")
        )
        df = pd.read_excel(filepath, header=None)
        single_patch = np.array(
            [[parse_cell(cell) for cell in row] for row in df.values]
        )
        self.tactiles_position_3D_H = np.repeat(
            single_patch[None, :, :], 5, axis=0
        )  # 5*12*8*4
        self.tactiles_position_3D_H[4, :, :, 2] += 12e-3

    def _init_pcb(self, port: str, timeout: float = 1.0):
        from .pcb_comm.serial_comm import PCBSerialInterface

        self.serial_interface = PCBSerialInterface(port=port, timeout=timeout)

    def _init_camera(self):
        from .camera_port.obbecdevicemanager import OrbbecCamera

        self.camera = OrbbecCamera()
        self.camera.init_camera()
        time.sleep(1)
        for _ in range(5):  # warm-up
            self.serial_interface.trigger_and_read()

    def set_joint_angle(self, data: np.ndarray):
        if self.use_motor:
            self.motor_driver.set_pos(data)
            return None

    def get_data(self):
        """
        Collects all updated sensor and actuator data.
        """
        self.upd_data()
        return {
            "base_rgb": self.rgb_image_array.copy(),
            "base_depth": self.depth_image_array.copy(),
            "joint_positions": self.hand_joint_positions.copy(),
            "joint_velocities": self.hand_joint_velocity.copy(),
            "joint_current": self.hand_joint_current.copy(),
            "touch": self.tactile_tensor.copy(),
            "touch_3D": self.tactile_tensor_3D.copy(),
        }

    def upd_data(self):
        """
        Core threaded data update. Reads motor states, tactile matrix, and RGB-D image.
        """

        def update_motor_state():
            if self.use_motor:
                (
                    self.hand_joint_positions,
                    self.hand_joint_velocity,
                    self.hand_joint_current,
                ) = self.motor_driver.read_pos_vel_cur()
                self.update_tactile_positions()

        def update_tactile_data():
            if self.use_pcb:
                try:
                    tactile_data = (
                        self.serial_interface.trigger_and_read()
                    )  # shape=(5, 96)
                except Exception as e:
                    raise RuntimeError(f"Tactile read failed: {e}")
                thread3.start()

                # Reshape and reorder tactile data
                self.tactile_tensor = tactile_data.reshape(self.tactile_tensor_shape)
                self.tactile_tensor = np.flip(self.tactile_tensor, axis=(1, 2))[
                    self.tactile_order_list
                ]
            else:
                thread3.start()

        def update_camera_data():
            if self.use_camera:
                bgr, depth = self.camera.get_latest_frames(device_index=0, timeout=0.5)

                while bgr is None:
                    print("Retrying RGB-D capture...")
                    self.serial_interface.trigger_and_read()
                    time.sleep(0.5)
                    bgr, depth = self.camera.get_latest_frames(
                        device_index=0, timeout=0.5
                    )

                rgb = cv2.cvtColor(bgr, cv2.COLOR_BGR2RGB)
                self.rgb_image_array = np.expand_dims(rgb, axis=0)
                self.depth_image_array = np.expand_dims(depth, axis=0)

        thread1 = threading.Thread(target=update_motor_state)
        thread2 = threading.Thread(target=update_tactile_data)
        thread3 = threading.Thread(target=update_camera_data)

        thread1.start()
        thread2.start()

        thread1.join()
        thread2.join()

        self.tactile_tensor_3D[..., -1] = self.tactile_tensor

        thread3.join()

    def update_tactile_positions(self):
        q = self.hand_joint_positions[self.real2pin]
        self.hand_model.set_current_qpos(q)
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

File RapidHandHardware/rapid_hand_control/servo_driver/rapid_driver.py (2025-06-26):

import os
import json
import numpy as np
from datetime import datetime
from .dynamixel_client import DynamixelClient


class RapidDriver:
    """
    A control interface for a Dynamixel-based hand or manipulator.

    Responsibilities:
    - Initialize servo parameters from a JSON config (e.g., PID gains, current limit).
    - Read joint states (position, velocity, current).
    - Convert RAPID pose vectors to servo commands using joint mapping.
    - Save/restore configuration for reuse and tuning.
    """

    def __init__(self, config_path=None, port="/dev/ttyUSB0", init_set=False):
        if config_path is None:
            config_path = os.path.join(os.path.dirname(__file__), "rapid_full.json")
        self.config_path = config_path
        self.config = self._load_config(config_path)

        # Initial values
        self.jointmap = self.config["init"]["jointmap"]
        self.kP = np.array(self.config["init"]["kP"], dtype=np.uint16)
        self.kI = np.array(self.config["init"]["kI"], dtype=np.uint16)
        self.kD = np.array(self.config["init"]["kD"], dtype=np.uint16)
        self.curr_lim = np.array(self.config["init"]["curr_lim"], dtype=np.uint16)
        self.init_pos = np.array(self.config["init"]["init_pos"], dtype=np.float32)

        self.prev_pos = self.curr_pos = self.init_pos.copy()
        self.motors = list(range(len(self.init_pos)))

        try:
            self.dxl_client = DynamixelClient(self.motors, port, baudrate=4000000)
            self.dxl_client.connect()
        except Exception as e:
            raise RuntimeError(f"Failed to connect to Dynamixel on {port}: {e}")

        # Motor configuration
        self._apply_initial_motor_config()

        if init_set:
            self.dxl_client.write_desired_pos(self.motors, self.init_pos)

    def _apply_initial_motor_config(self):
        """Apply torque settings, PID gains, and current limits."""
        self.dxl_client.sync_write(self.motors, np.ones(len(self.motors)) * 5, 11, 1)
        self.dxl_client.set_torque_enabled(self.motors, True)
        self.dxl_client.sync_write(self.motors, self.kP, 84, 2)
        self.dxl_client.sync_write(self.motors, self.kI, 82, 2)
        self.dxl_client.sync_write(self.motors, self.kD, 80, 2)
        self.dxl_client.sync_write(self.motors, self.curr_lim, 102, 2)

    def _load_config(self, file_path):
        if not os.path.exists(file_path):
            raise FileNotFoundError(f"Config file not found: {file_path}")
        with open(file_path, "r", encoding="utf-8") as f:
            return json.load(f)

    def save_config(self, save_path=None):
        """Save the current PID gains and state to a JSON file."""
        if save_path is None:
            os.makedirs("args", exist_ok=True)
            timestamp = datetime.now().strftime("%Y%m%d_%H%M%S")
            save_path = f"args/rapid_{timestamp}.json"

        config_to_save = {
            "init": {
                "kP": self.kP.tolist(),
                "kI": self.kI.tolist(),
                "kD": self.kD.tolist(),
                "curr_lim": self.curr_lim.tolist(),
                "pos": self.curr_pos.tolist(),
            }
        }

        with open(save_path, "w", encoding="utf-8") as f:
            json.dump(config_to_save, f, indent=4)
        print(f"[✓] Configuration saved to {save_path}")

    def set_servo(self, pose: np.ndarray):
        """Send raw joint command (in radians) to all motors."""
        self.dxl_client.write_desired_pos(self.motors, pose)

    def set_pos(self, pose: np.ndarray):
        """Map RAPID pose (e.g., 20 DOF) into servo positions and send to hardware."""
        assert len(pose) == len(self.jointmap), "Invalid pose vector length."

        self.prev_pos = self.curr_pos.copy()
        temp = np.zeros_like(self.init_pos)

        for i, mappings in enumerate(self.jointmap):
            for motor_idx, weight in mappings:
                temp[motor_idx] += pose[i] * weight

        self.curr_pos = self.init_pos + temp
        self.dxl_client.write_desired_pos(self.motors, self.curr_pos)

    def read_pos_vel_cur(self):
        """Returns a RAPID pose vector (backmapped) and servo states."""
        pos, vel, cur = self.dxl_client.read_pos_vel_cur()
        delta = pos - self.init_pos
        pose = self._backproject_pose(delta)
        return pose, vel, cur

    def read_pos(self):
        delta = self.dxl_client.read_pos() - self.init_pos
        return self._backproject_pose(delta)

    def read_vel(self):
        return self.dxl_client.read_vel()

    def read_cur(self):
        return self.dxl_client.read_cur()

    def _backproject_pose(self, delta: np.ndarray) -> np.ndarray:
        """Convert joint angles (rad) to abstracted RAPID pose space."""
        pose = np.zeros(len(self.jointmap))
        for i, mappings in enumerate(self.jointmap):
            for motor_idx, weight in mappings:
                pose[i] += delta[motor_idx] / weight / len(mappings)
        return pose

    def setkP(self, data):
        self._update_gain("kP", 84, data)

    def setkI(self, data):
        self._update_gain("kI", 82, data)

    def setkD(self, data):
        self._update_gain("kD", 80, data)

    def set_curr_lim(self, data):
        self._update_gain("curr_lim", 102, data)

    def _update_gain(self, name: str, address: int, data):
        """Update a specific control parameter (PID or current limit)."""
        setattr(self, name, np.array(data, dtype=np.uint16))
        self.dxl_client.sync_write(self.motors, getattr(self, name), address, 2)

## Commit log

2025-06-26 Initial commit for open source
    [BOM_Board1_PCB1.xlsx, F1.STL, F2.STL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]
2025-07-08 Upload PCB layout
